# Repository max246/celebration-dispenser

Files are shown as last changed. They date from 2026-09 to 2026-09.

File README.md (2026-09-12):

# Celebration Dispenser




A button-triggered desktop celebration machine. Press the button and it dispenses
a treat (confetti, candy, sprinkles — your choice) via a stepper-driven mechanism
while a WS2812 LED strip runs a light show and a sound plays over a small
amplifier.

This repo has two halves:

| Folder | What's inside |
|---|---|
| [`hardware/`](hardware/) | 3D-printable STL parts (finger-wheel dispenser) + bill of materials + assembly guide |
| [`firmware/`](firmware/) | ESP32-S2 firmware (PlatformIO / Arduino) that runs the dispenser |

## How it works

```
        [ push button ]
              │  press
              ▼
    ┌──────────────┐   UART+step/dir   ┌──────────┐
    │  ESP32-S2    │ ────────────────▶ │ TMC2209  │─▶ NEMA 17 ─▶ finger wheel
    │  Feather     │ ◀──── DIAG stall ─┘ (auto-unjam on jam)
    │  (WiFi)      │ ────────────────▶ WS2812 strip ─▶ light show
    │              │ ──I2S──▶ MAX98357A ─▶ speaker ─▶ audio (from on-board flash)
    └──────────────┘
```

On a button press the ESP32-S2 runs a single **celebration sequence**: the
TMC2209 turns the finger wheel to dispense a portion (backing off and retrying if
StallGuard detects a jam), a rainbow sweeps the LED strip, and a sound plays from
on-board flash through the MAX98357A — all at the same time — then it returns to
idle.

## Quick start

1. **Print & wire the hardware** — see [`hardware/README.md`](hardware/README.md)
   and the wiring diagram in [`docs/WIRING.md`](docs/WIRING.md).
2. **Flash the firmware** — see [`firmware/README.md`](firmware/README.md). Bench-test
   the motor first with `pio run -e motortest -t upload`.
3. Power it up, press the button, celebrate.

## Tuning

Almost everything you'll want to change (dispense amount, speed, stall
sensitivity, LED count, volume, GPIO pins) lives in
[`firmware/include/config.h`](firmware/include/config.h); the celebration and
idle sounds are 16-bit WAV files in `firmware/data/` (uploaded with
`pio run -t uploadfs`). The printable parts and assembly guide live in
[`hardware/`](hardware/).

## License

[MIT](LICENSE) © Christian Bianchini. Note the bundled audio in `music/` /
`firmware/data/` is git-ignored and not covered by this license — supply your
own sounds.

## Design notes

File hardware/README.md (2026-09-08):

# Hardware

3D-printable parts and assembly for the Celebration Dispenser.

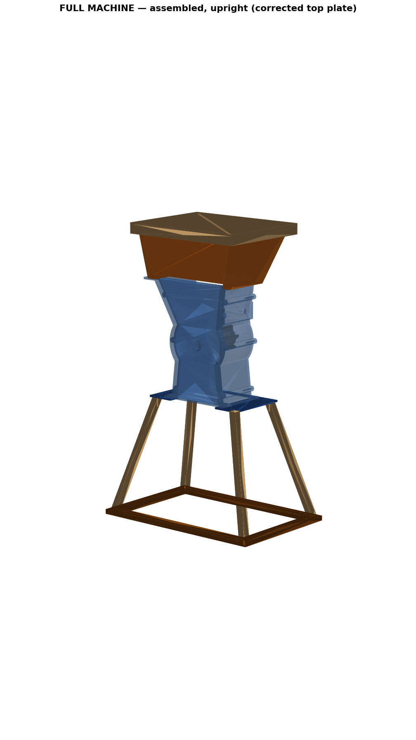
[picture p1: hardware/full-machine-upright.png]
Full machine — assembled, upright


The mechanism is a **finger wheel**: a printed wheel fitted with flexible
zip-tie "fingers" spins inside a housing, driven by the stepper. Candy sits in
the hopper above; the sweeping fingers agitate it and meter it through the
housing outlet. One button press = one dispense.

The fingers reach out to a wide annulus so they sweep close to the housing wall
(this is the `v5` wheel — cross-section below):

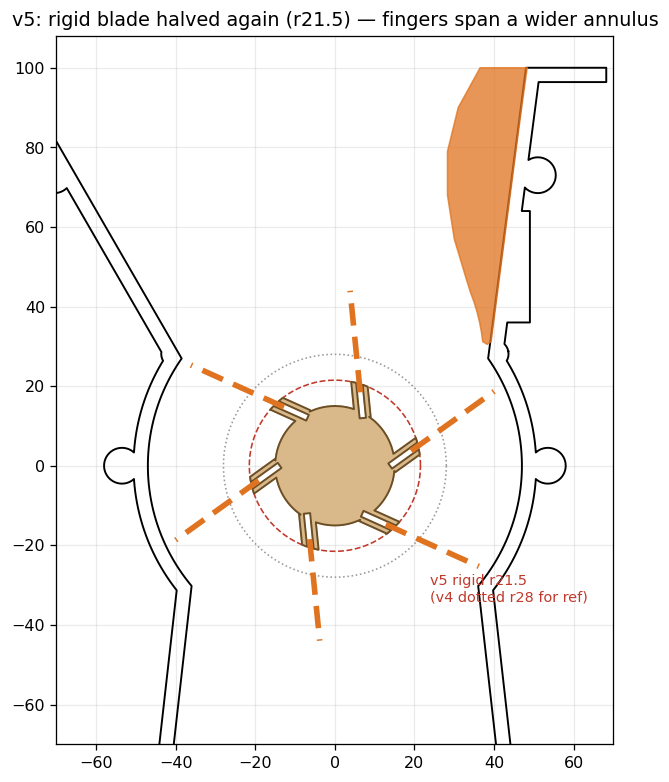
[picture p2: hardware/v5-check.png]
v5 finger-wheel cross-section


## Parts to print

Files in [`stl/`](stl/), with measured bounding boxes so you can check they fit
your printer's bed. Preview renders are in [`stl/previews/`](stl/previews/).

| File | Print qty | Size X×Y×Z (mm) | Role |
|---|---|---|---|
| `housing-main-608.stl` | 1 | 174 × 195 × 92  | Main housing; holds the wheel + 608 bearings |
| `housing-lid-608.stl` | 1 | 174 × 195 × 10  | Housing lid (6× M3×8) |
| `rear-bearing-block.stl` | 1 | 40 × 40 × 10 | Rear 608-bearing block; supports the shaft's back end |
| `rejector-ramp-v2.stl` | 1 | 20 × 70 × 80 | Rejector ramp inside the housing (sheds excess candy) |
| `vane-wheel-v5-half-blade.stl` | 1 | 90 × 90 × 80 | Finger wheel — takes the zip-tie fingers |
| `wheel-drive-pinion-12T.stl` | 1 | 21 × 21 × 20 | 12T pinion on the NEMA 17 shaft |
| `wheel-driven-gear-36T-v2.stl` | 1 | 57 × 57 × 28 | 36T gear on the 8 mm wheel shaft (3:1) |
| `wheel-motor-bracket-v5-counterbore.stl` | 1 | 117 × 40 × 26 | Motor bracket (holds the NEMA 17) |
| `hopper-extension-onepiece.stl`  | 1 | 204 × 94 × 150  | Hopper body; bolts to the housing mouth |
| `hopper-lid.stl` | 1 | 212 × 18 × 166  | Hopper lid (friction fit, no hardware) |
| `stand-top-plate.stl` | 1 | 184 × 106 × 3 | Plate the housing mounts to |
| `stand-leg-single.stl` | **4** | 70 × 200 × 57 | Stand leg — **print 4** (1 + mirror 3 in your slicer) |
| `stand-bottom-frame.stl` | 1 | 300 × 8 × 200 | Base frame tying the legs together |

> `housing-main` and the hopper are large (≈195–212 mm on their longest edge) —
> confirm they fit your build plate before slicing.

### Suggested print settings

- **Material:** PLA is fine indoors; PETG if it'll see any heat/sun.
- **Layer height:** 0.2 mm.
- **Walls / top / bottom:** 3 perimeters, 4 top/bottom layers.
- **Infill:** 20–30% (more for the finger wheel — it takes the load).
- **Supports:** likely needed on the housing (bearing pockets / overhangs) and
  possibly the hopper mouth — check each part in your slicer.

## Bill of materials (non-printed)

### Electronics

| Item | Qty | Notes |
|---|-----|---|
| Adafruit ESP32-S2 Feather | 1 | WiFi + 2 MB PSRAM (for streamed audio)  |
| NEMA 17 stepper motor | 1 | Drives the finger wheel |
| TMC2209 stepper driver | 1 | Silent; StallGuard stall-detect for auto-unjam |
| MAX98357A I2S amplifier | 1 | Plays the streamed celebration audio |
| Speaker, 4–8 Ω | 1 | To the MAX98357A output |
| WS2812 / NeoPixel strip | 1 | 16 px default (see `firmware/config.h`) |
| Momentary push button | 1 | |
| 12 V power supply (≥1 A) | 1 | For the motor via the driver |
| 100 µF cap, 330–470 Ω + 1 kΩ resistors | 1ea | Driver VM cap; LED data line; TMC2209 UART |

Wiring and pin map: [`../firmware/README.md`](../firmware/README.md).

### Mechanical fasteners

| Item | Qty  | Where |
|---|---|---|
| Zip ties (~2.5 mm wide) | 30 | Wheel **fingers** — 24 mm proud, glued in the slots |
| Super glue (CA) | — | To fix the zip-tie fingers in their slots |
| 608 bearings (8 mm bore) | 2 | Front seat in the housing + one in the rear-bearing-block |
| 8 mm shaft | 1 | Rides in the 608 bearings |
| M3 screws | 4 | Rear-bearing-block → housing rear |
| M3 grub / set screw | 3 | 1 locks the wheel, 2 lock the 36T gear, to the shaft |
| M3 × 25 screws | 2 | Motor-bracket standoffs (bottom out on the lid) |
| M3 × 8 screws | 6 | Housing lid → housing |
| M4 bolt + nut | 4 | Hopper extension → housing mouth-flange  |
| M4 × 20 screws | 4 | Stand: up into the leg bottoms |
| M3 × 16 screws | 4 | Stand: top plate down into the leg tops  |

## Assembly

### Section 1 — Stand

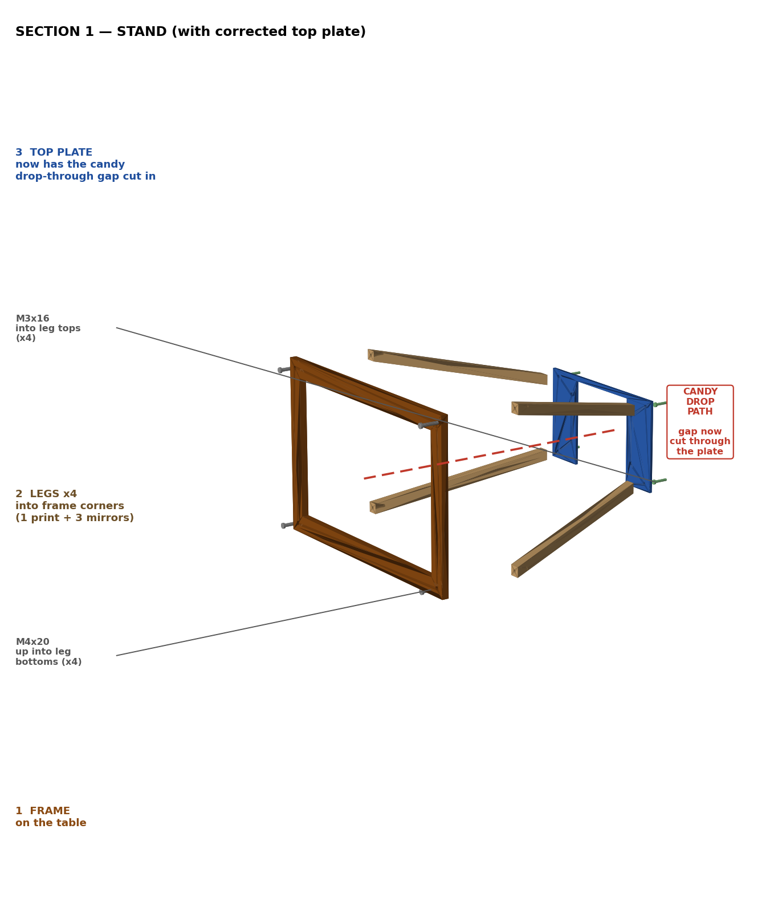
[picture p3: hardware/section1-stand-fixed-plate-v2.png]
Section 1 — Stand (with hardware)


1. **Frame** — lay `stand-bottom-frame` flat on the table.
2. **Legs ×4** — fit a leg into each frame corner and fasten from below with
   **M4 × 20** screws (×4). Print the leg once and **mirror 3 copies** in your
   slicer so all four corners match.
3. **Top plate** — set `stand-top-plate` onto the leg tops and secure with
   **M3 × 16** screws (×4).

### Section 2 — Housing core

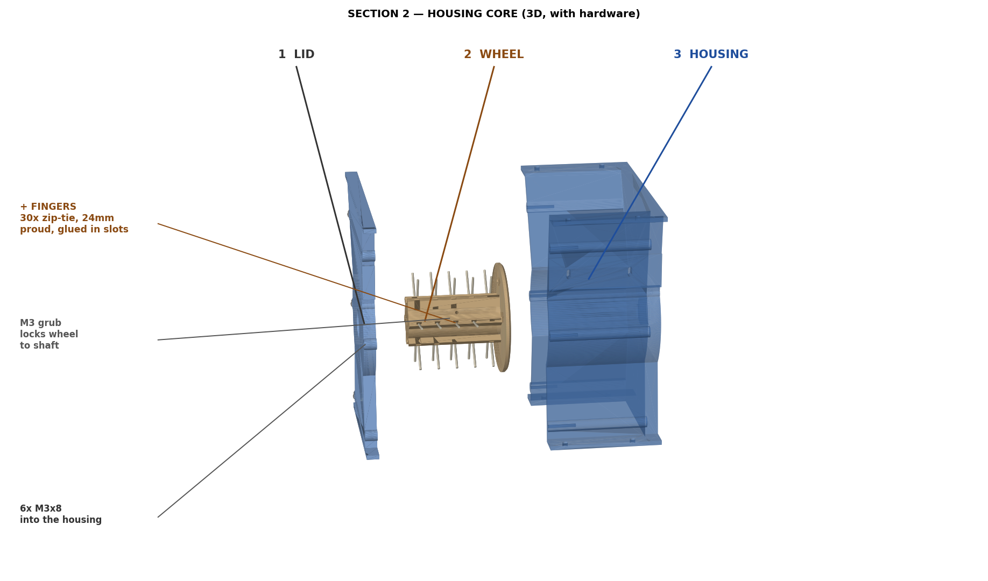
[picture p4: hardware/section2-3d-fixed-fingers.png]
Section 2 — Housing core (with hardware)


1. **Fingers** — push **30 zip ties** into the wheel's slots so ~**24 mm**
   stands proud, and **glue** them in place.
2. **Shaft + bearings** — seat one **608 bearing** in the housing (front) and
   the other in `rear-bearing-block`, then run the **8 mm shaft** through both.
   Screw the rear-bearing-block to the back of the housing (**4× M3**).
3. **Finger wheel** — mount the wheel on the shaft and lock it with the
   **M3 grub screw**.
4. **Close the lid** — `housing-lid-608` onto `housing-main-608` with
   **6× M3×8**, leaving the 8 mm shaft protruding for the drive train.

### Section 2b — Drive train

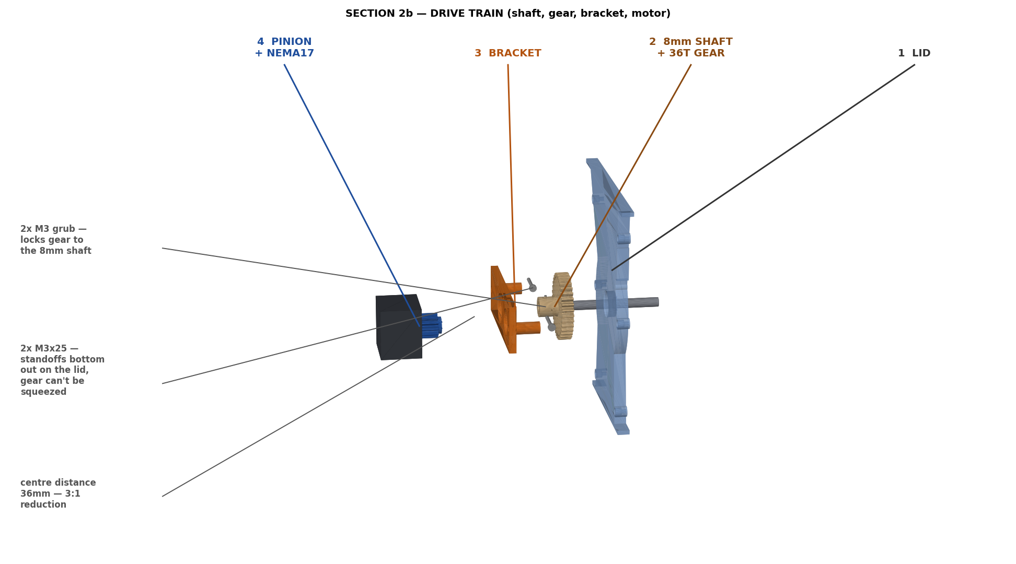
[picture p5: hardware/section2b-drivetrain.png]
Section 2b — Drive train (shaft, gear, bracket, motor)


1. **36T gear** — slide `wheel-driven-gear-36T-v2` onto the protruding 8 mm
   shaft and lock it with **2× M3 grub** screws.
2. **12T pinion** — fit `wheel-drive-pinion-12T` onto the NEMA 17 shaft.
3. **Bracket + motor** — bolt the motor to `wheel-motor-bracket-v5-counterbore`
   and fasten the bracket to the lid on **2× M3×25** standoffs. The standoffs
   bottom out on the lid so the gears can't be squeezed together; the pinion
   meshes with the 36T gear at a **36 mm centre distance** for a **3:1
   reduction**.

### Section 2c — Rejector ramp

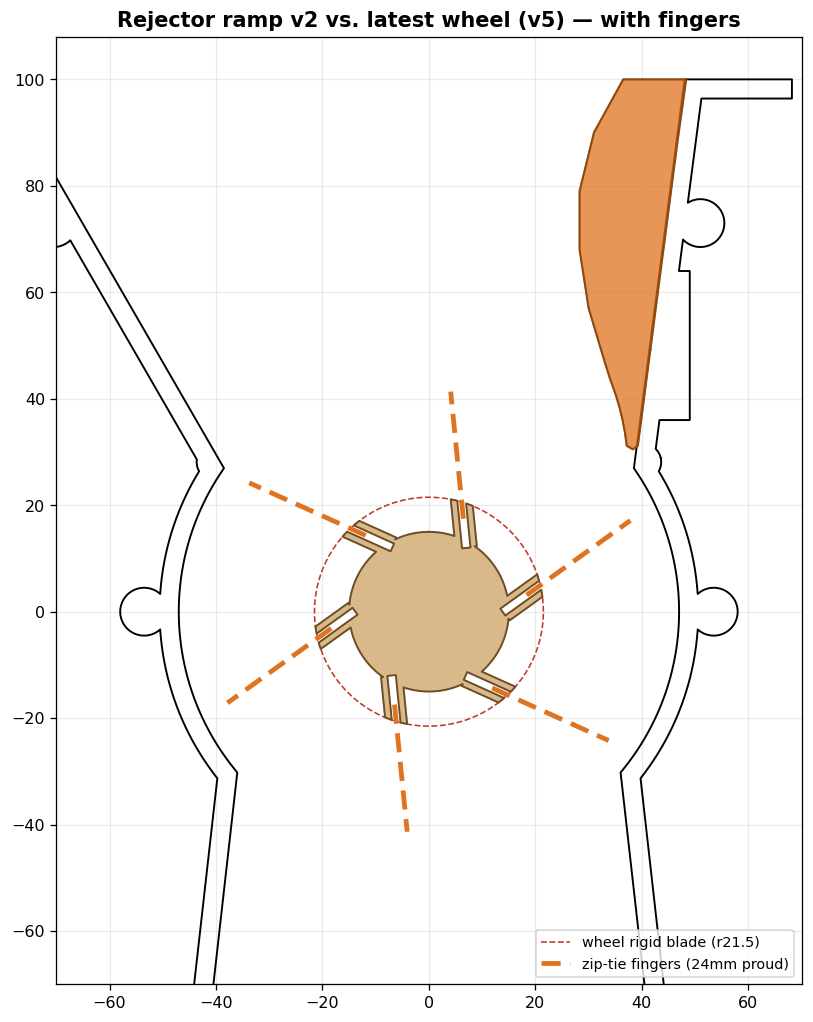
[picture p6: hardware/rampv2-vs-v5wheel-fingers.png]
Rejector ramp v2 vs. the v5 finger wheel


`rejector-ramp-v2` mounts against the housing's **feed-side wall** (top, below
the hopper mouth). Its lower tip sits **just outside the finger sweep** — the
zip-tie fingers reach ~24 mm proud of the r21.5 wheel — forming a narrowing gap.
As the wheel turns, surplus candy is pushed back up the ramp toward the hopper
while the fingers carry only a metered amount down to the outlet.

- Set the ramp tip to **just clear the finger tips** (no contact) — this gap is
  what sets the portion, so tune it against your candy size.
- The fit view shows no fasteners: the ramp seats against the wall (glue or a
  printed slot). Confirm how yours attaches and I'll note it here.

### Section 3 — Hopper stack

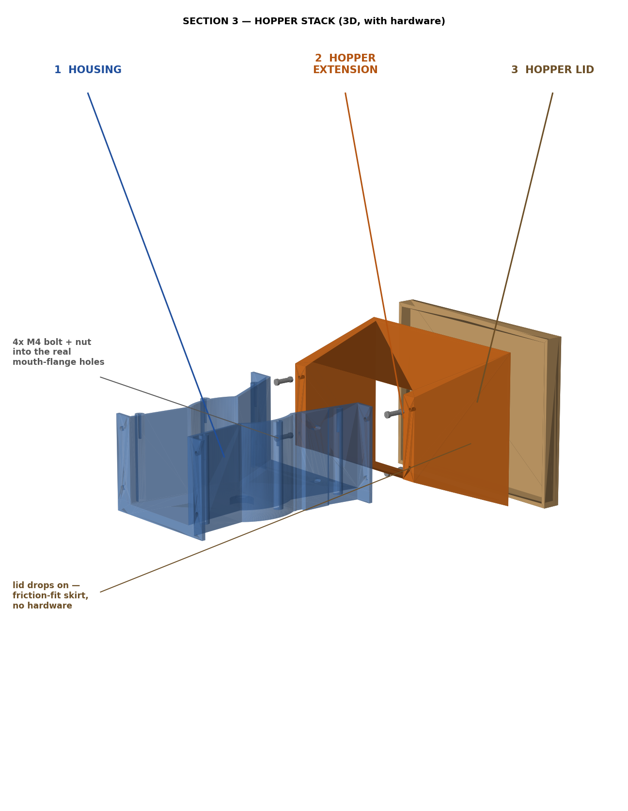
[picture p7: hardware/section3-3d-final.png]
Section 3 — Hopper stack (with hardware)


1. **Hopper extension** — bolt `hopper-extension-onepiece` to the housing's
   mouth-flange holes with **4× M4 bolt + nut**.
2. **Hopper lid** — `hopper-lid` just **drops on** (friction-fit skirt, no
   hardware).

### Final

Mount the housing on the stand's top plate, wire the electronics per the
firmware README (share all grounds), load candy, flash, and press the button.

## Tuning the dispense

Mechanics are fixed by the prints, but how much/how fast is dispensed is set in
the firmware — see [`../firmware/include/config.h`](../firmware/include/config.h):
`DISPENSE_REVS` (portion size), `STEPPER_MAX_SPEED` / `STEPPER_ACCEL` (speed),
`DISPENSE_CW` (direction), `MOTOR_CURRENT_MA`, and `STALL_THRESHOLD` (jam
sensitivity for the auto-unjam).

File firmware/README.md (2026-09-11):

# Firmware

ESP32-S2 firmware for the Celebration Dispenser, built with
[PlatformIO](https://platformio.org/) on the Arduino framework.

**Board:** Adafruit ESP32-S2 Feather (4 MB flash, 2 MB PSRAM).

## Layout

```
firmware/
├── platformio.ini            # board + pinned dependencies
├── data/                     # audio WAVs -> LittleFS (celebrate.wav, idle.wav)
├── include/
│   ├── config.h              # ALL tunables: pins, dispense, stall, LEDs, audio
│   └── secrets.h.example      # only for the streaming audio *test* (git-ignored)
└── src/
    ├── main.cpp              # button + celebration state machine
    ├── motor.{h,cpp}         # TMC2209 (UART) + AccelStepper + StallGuard unjam
    ├── audio_player.{h,cpp}  # raw WAV (preloaded to PSRAM) over I2S (MAX98357A)
    └── lights.{h,cpp}        # non-blocking WS2812 rainbow show
```

## First-time setup

Audio plays from on-board flash (no WiFi — see the note in **Behavior**). Put your
sounds in [`data/`](data/) and upload them once:

```bash
cd firmware
# put celebrate.wav and idle.wav in data/  (16-bit mono WAV — see data/README.md)
pio run -t uploadfs      # writes data/ to the LittleFS partition
pio run -t upload        # flash the firmware
```

The main firmware needs **no `secrets.h`** — that's only for the optional
streaming audio test.

## Wiring

Default pin map (edit in [`include/config.h`](include/config.h)). Pins are named
by the Feather's **silkscreen labels**. For a wiring diagram of the driver +
audio, see [`docs/WIRING.md`](../docs/WIRING.md).

### TMC2209 stepper driver

| Feather | TMC2209 | Notes |
|---|---|---|
| D5 | STEP | |
| D6 | DIR | |
| D9 | EN | active LOW; released when idle |
| D10 | DIAG | driver pulls HIGH on stall → triggers unjam |
| TX | PDN_UART | **through a 1 kΩ resistor** |
| RX | PDN_UART | direct (single-wire UART node) |
| 3.3V | VIO | logic supply |
| GND | GND | common ground |

Also on the driver: **VM + GND** → motor supply (e.g. 12 V) with a **100 µF cap**
across them; coil pairs → **1A/1B, 2A/2B**; **MS1 + MS2 → GND** (sets UART address
`0b00`, matching `TMC_ADDRESS`). Set the run current with `MOTOR_CURRENT_MA` in
`config.h` (it's configured over UART — no Vref pot to tune).

### Audio — MAX98357A (I2S)

| Feather | MAX98357A | Notes |
|---|---|---|
| SCK | BCLK | |
| MO | LRC | word-select |
| MI | DIN | |
| USB/5V  | VIN | 2.5–5.5 V |
| GND | GND | |

Speaker (4–8 Ω) to the amp's **+ / –** screw terminals. Leave `SD` unconnected
(enabled) and `GAIN` unconnected for the default 9 dB.

### Button & LEDs

| Feather | To |
|---|---|
| D11 | push button → **GND** (internal pull-up) |
| D12 | WS2812 **DIN** (330–470 Ω in series) |

> ⚠️ Share **all grounds** (Feather, driver logic, motor supply, amp, LEDs).
> Don't power the motor from the Feather — use a dedicated motor supply.

## Build & flash

```bash
pio run                 # compile
pio run -t upload       # flash over USB (native USB CDC on the S2)
pio device monitor      # serial log @ 115200
```

On boot the serial log prints whether LittleFS mounted and the TMC2209 version
(`0x21` = UART link good).

## Bench test (motor)

Before wiring the whole thing, bring up just the TMC2209 + motor with the
standalone test in `src/tools/motor_test.cpp` — a separate PlatformIO env that
needs **no WiFi, audio, or `secrets.h`**:

```bash
pio run -e motortest -t upload
pio device monitor -e motortest
```

It prints the driver version (`0x21` = UART OK), jogs the wheel ±1 revolution,
and streams `speed` / `DIAG` / `SG_RESULT` so you can confirm motion and tune
`STALL_THRESHOLD` (push on the wheel and watch `SG_RESULT` drop toward 0 / `DIAG`
go HIGH). Wiring for this is the TMC2209 half of
[`docs/WIRING.md`](../docs/WIRING.md).

## Bench test (audio)

Two audio tools, both separate envs (wiring is the MAX98357A half of
[`docs/WIRING.md`](../docs/WIRING.md)):

- **`tonetest`** — the definitive amp/wiring check. Plays a clean 440 Hz sine
  straight to I2S, no WiFi/decode/library. If this is clean, the amp, speaker,
  and I2S wiring are all good.
  ```bash
  pio run -e tonetest -t upload
  ```
- **`wavtest`** — the real audio path: preloads a WAV into PSRAM and plays it
  from RAM, no WiFi/motor/button. This is how you verify the celebration/idle
  audio in isolation. Put a `data/idle.wav` first.
  ```bash
  pio run -e wavtest -t upload     # flash + partition table
  pio run -e wavtest -t uploadfs   # upload data/idle.wav
  ```
- **`fstest` / `audiotest`** — diagnostic history: `fstest` plays MP3 from flash
  (decode can't keep up → crackles) and `audiotest` streams MP3 over WiFi
  (streaming crackles too). These are why the firmware uses raw WAV from PSRAM.
  Kept for reference / for an S3.

## Behavior

Audio is **16-bit WAV preloaded into PSRAM** and fed to I2S from RAM — no WiFi,
no MP3 decode, no flash access during playback. On the single-core S2 that's the
only path that stays clean (streaming and MP3 decode both crackle once their
buffer drains; playing raw PCM from RAM does not). Feeding is non-blocking, so
the motor and LEDs keep running while a sound plays.

While **idle**, `idle.wav` loops over the amp (at `IDLE_VOLUME`) — set
`ENABLE_IDLE_AUDIO = false` to disable it.

Press the button → one **celebration**, all at once:
- **Dispense:** the TMC2209 turns the finger wheel `DISPENSE_REVS` revolutions.
- **Auto-unjam:** if the candy jams, the motor stalls, DIAG goes HIGH, and the
  firmware backs off `UNJAM_REVERSE_STEPS` and retries — up to
  `UNJAM_MAX_RETRIES` times before giving up and logging a jam.
- **Lights:** a rainbow sweeps the WS2812 strip.
- **Audio:** the idle loop is interrupted and `celebrate.wav` plays once (at
  `CELEBRATION_VOLUME`); the idle loop resumes when it ends.

Presses during a celebration are ignored. When idle, the motor is de-energized
(silent, cool) unless `HOLD_TORQUE_WHEN_IDLE = true`.

## Tuning cheatsheet

| Want to… | Change in `config.h` |
|---|---|
| Dispense more/less | `DISPENSE_REVS` (wheel revolutions) |
| Change the gears | `GEAR_RATIO` (default 36T/12T = 3:1) |
| Dispense faster/slower | `STEPPER_MAX_SPEED`, `STEPPER_ACCEL` |
| Reverse direction | `DISPENSE_CW` |
| Motor current | `MOTOR_CURRENT_MA` |
| Stall sensitivity | `STALL_THRESHOLD` (higher = trips easier) |
| Unjam back-off / retries | `UNJAM_REVERSE_STEPS`, `UNJAM_MAX_RETRIES`|
| Quieter vs. more torque | `USE_STEALTHCHOP` |
| More/fewer LEDs, dimmer | `LED_COUNT`, `LED_BRIGHTNESS` |
| Volumes | `CELEBRATION_VOLUME`, `IDLE_VOLUME` (0–21) |
| Idle ambience on/off | `ENABLE_IDLE_AUDIO` |
| Sound files | `AUDIO_FILE`, `IDLE_FILE` (in `data/`, then `uploadfs`) |

## Notes

- Main-firmware dependencies (pinned in `platformio.ini`): **AccelStepper**,
  **Adafruit NeoPixel**, **TMCStepper**. Audio is raw WAV via the ESP-IDF I2S
  driver — no MP3 library. Platform is `espressif32@6.9.0` (arduino-esp32 2.0.x).
  The `audiotest`/`fstest` diagnostic envs still pull **ESP32-audioI2S** `2.0.6`.
- The S2 is single-core, so audio, step generation, and the LEDs share one CPU.
  Audio is fed non-blocking from PSRAM, so it coexists fine; if you ever hear a
  hiccup under very fast dispensing, lower `STEPPER_MAX_SPEED`.

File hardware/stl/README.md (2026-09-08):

# STL files

The printable parts for the Celebration Dispenser (a finger-wheel dispenser on
608 bearings). See [`../README.md`](../README.md) for the parts table, print
settings, bill of materials, and assembly.

| File | Role |
|---|---|
| `housing-main-608.stl` | Main housing; holds the finger wheel + bearings |
| `housing-lid-608.stl` | Housing lid |
| `rear-bearing-block.stl` | Rear 608-bearing block (supports shaft)|
| `rejector-ramp-v2.stl` | Rejector ramp inside the housing |
| `vane-wheel-v5-half-blade.stl` | Finger wheel — takes the zip-tie fingers |
| `wheel-drive-pinion-12T.stl` | 12T pinion on the motor shaft |
| `wheel-driven-gear-36T-v2.stl` | 36T gear on the 8 mm wheel shaft (3:1) |
| `wheel-motor-bracket-v5-counterbore.stl` | Motor bracket (holds the NEMA 17) |
| `hopper-extension-onepiece.stl`  | Hopper body |
| `hopper-lid.stl` | Hopper lid |
| `stand-top-plate.stl` | Plate the housing mounts to |
| `stand-leg-single.stl` | One stand leg — print ×4 (1 + mirror 3)|
| `stand-bottom-frame.stl` | Base frame |

Preview renders of each part are in [`previews/`](previews/).

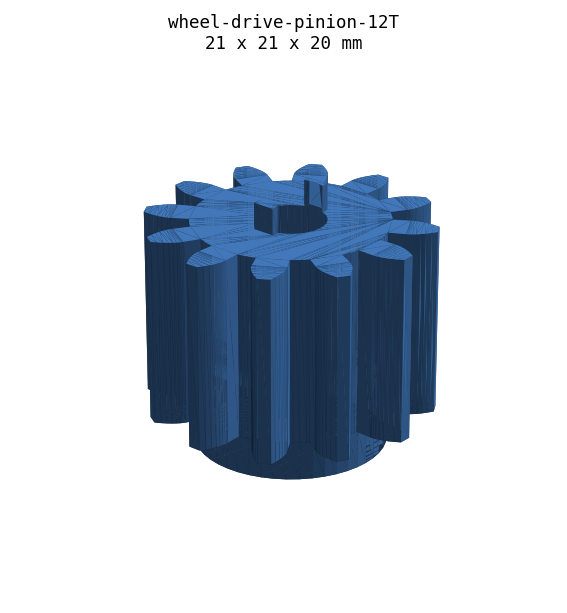
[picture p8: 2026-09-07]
hardware/stl/previews/wheel-drive-pinion-12T.png

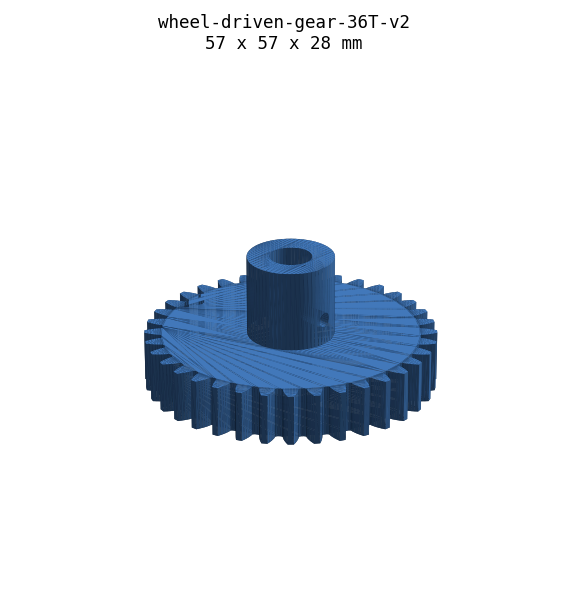
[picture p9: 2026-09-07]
hardware/stl/previews/wheel-driven-gear-36T-v2.png

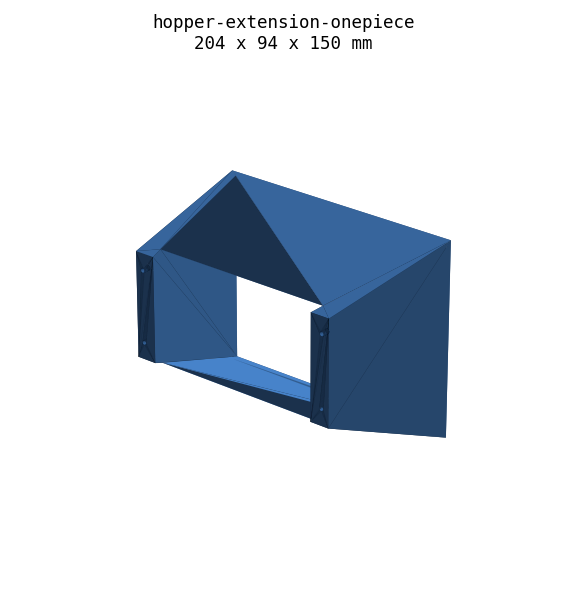
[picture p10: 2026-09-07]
hardware/stl/previews/hopper-extension-onepiece.png

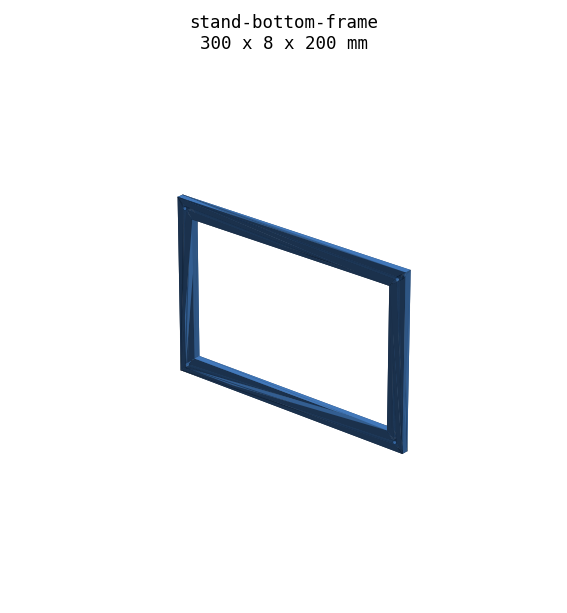
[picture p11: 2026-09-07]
hardware/stl/previews/stand-bottom-frame.png

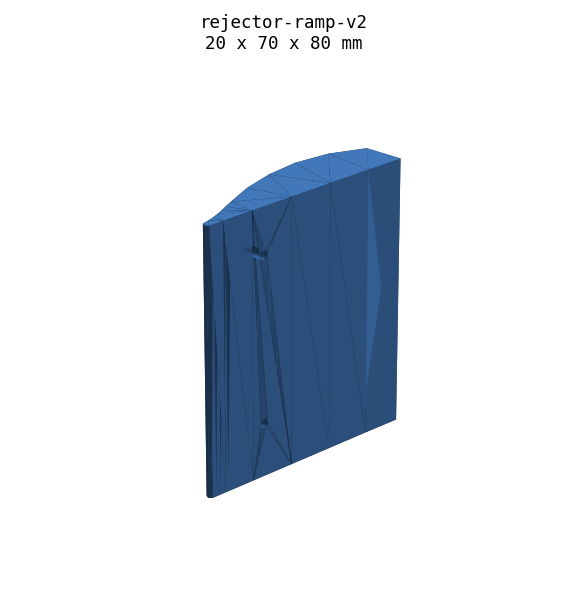
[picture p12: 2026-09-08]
hardware/stl/previews/rejector-ramp-v2.png

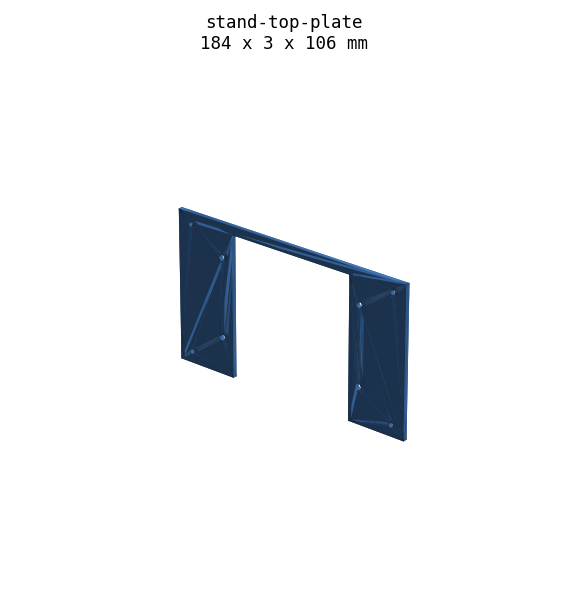
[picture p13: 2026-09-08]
hardware/stl/previews/stand-top-plate.png

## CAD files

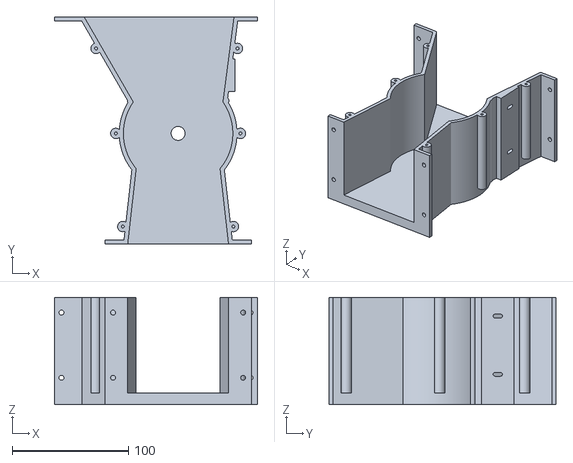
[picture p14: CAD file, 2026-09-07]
hardware/stl/housing-main-608.stl
174.4 x 195.0 x 92.0

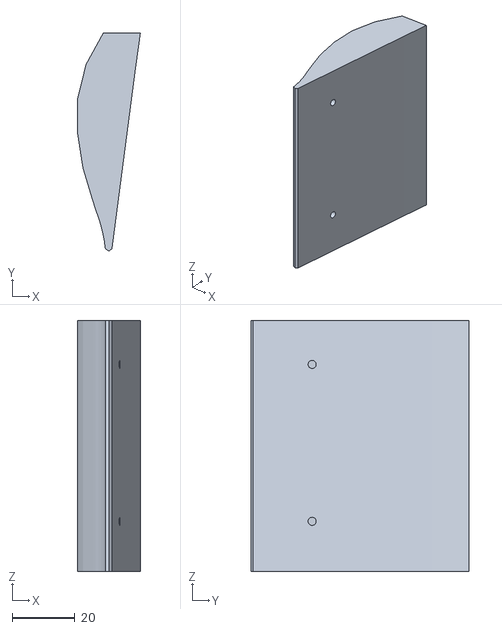
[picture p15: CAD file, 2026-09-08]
hardware/stl/rejector-ramp-v2.stl
20.0 x 69.5 x 80.0

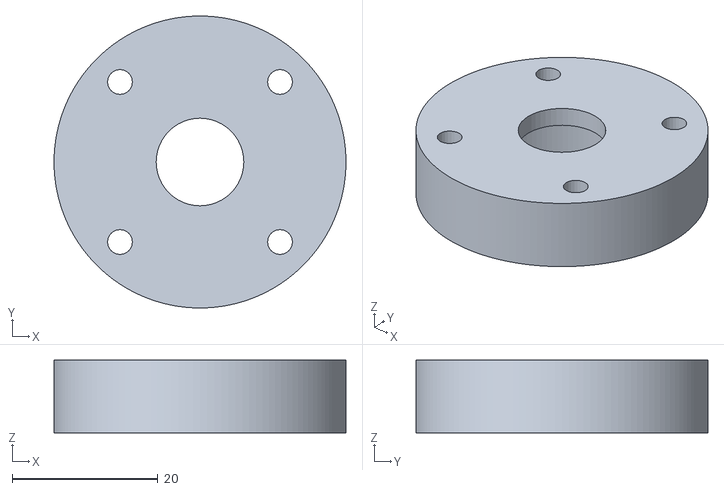
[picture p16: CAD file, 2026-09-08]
hardware/stl/rear-bearing-block.stl
40.0 x 40.0 x 10.0

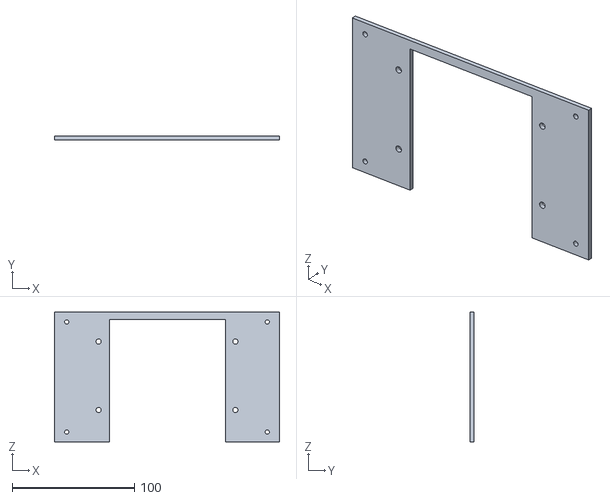
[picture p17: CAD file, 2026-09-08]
hardware/stl/stand-top-plate.stl
184.0 x 3.00 x 106.0

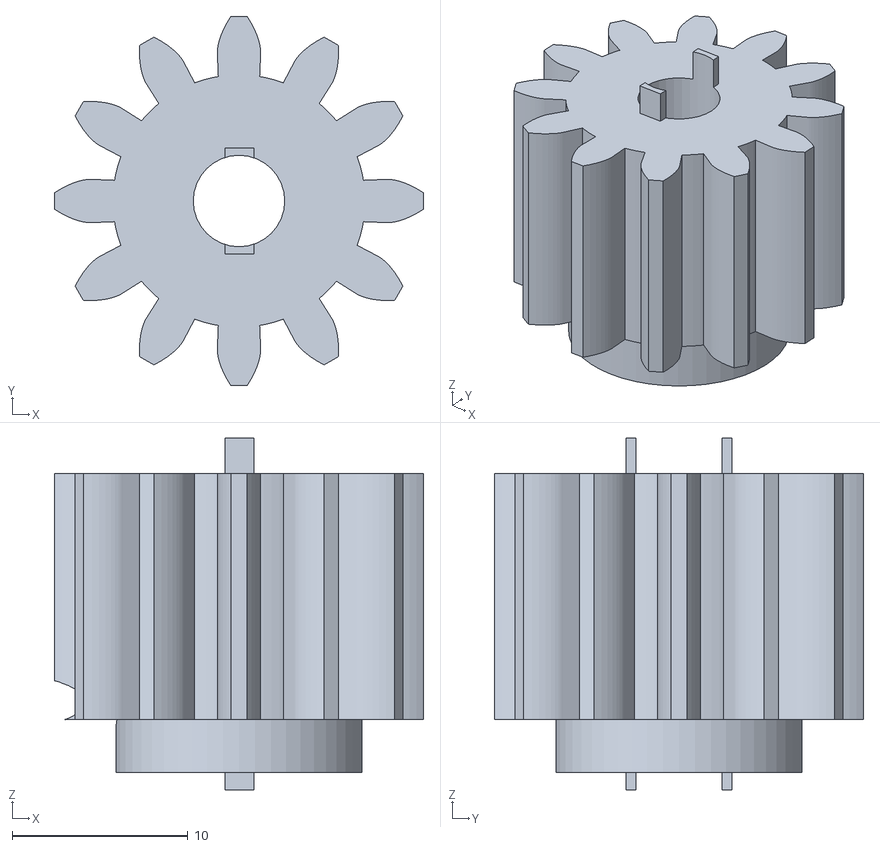
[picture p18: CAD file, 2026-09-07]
hardware/stl/wheel-drive-pinion-12T.stl
21.0 x 21.0 x 20.0

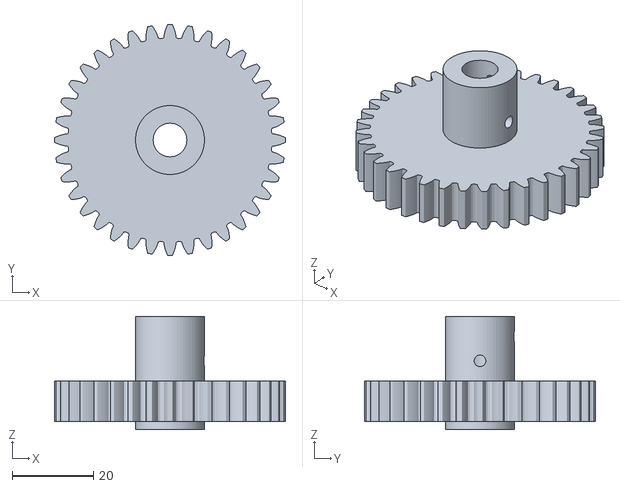
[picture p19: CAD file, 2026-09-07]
hardware/stl/wheel-driven-gear-36T-v2.stl
57.0 x 57.0 x 28.0

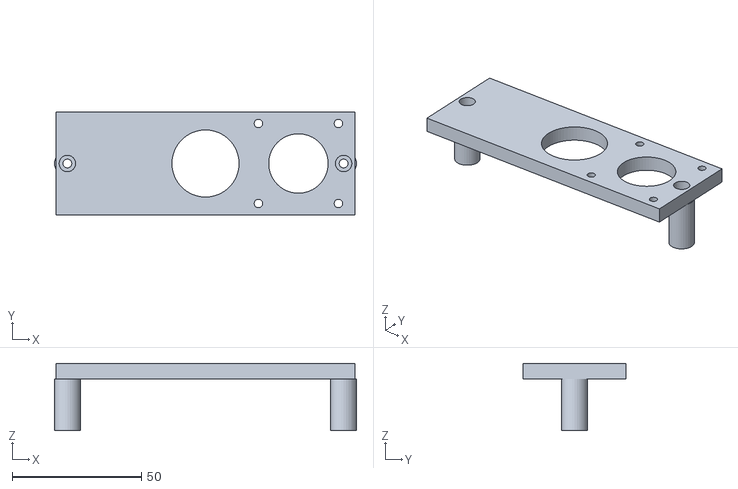
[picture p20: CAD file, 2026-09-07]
hardware/stl/wheel-motor-bracket-v5-counterbore.stl
117.0 x 40.0 x 26.0

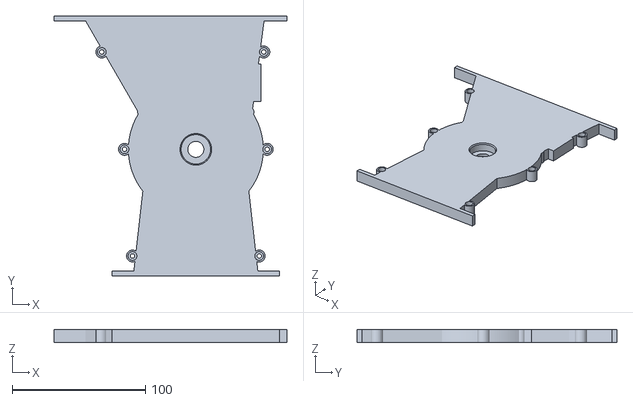
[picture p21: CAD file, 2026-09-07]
hardware/stl/housing-lid-608.stl
174.4 x 195.0 x 10.0

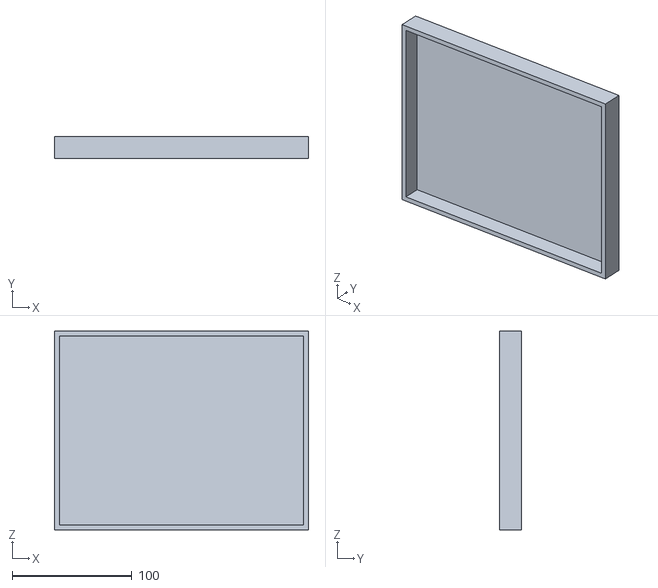
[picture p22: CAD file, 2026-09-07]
hardware/stl/hopper-lid.stl
212.0 x 18.0 x 166.0

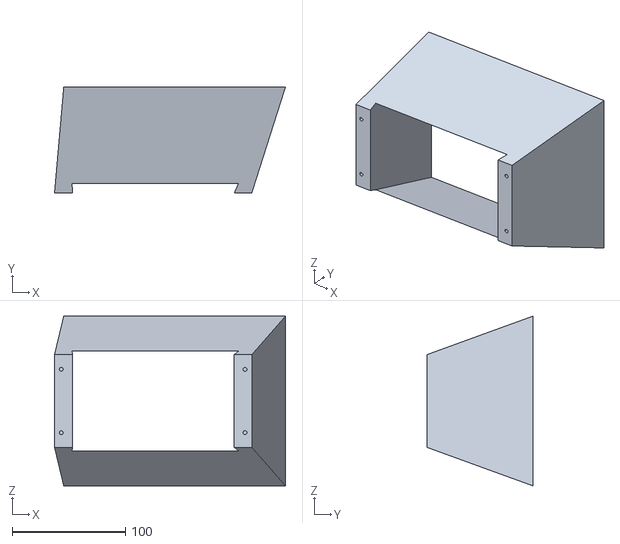
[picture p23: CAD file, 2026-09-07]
hardware/stl/hopper-extension-onepiece.stl
204.2 x 93.6 x 150.0

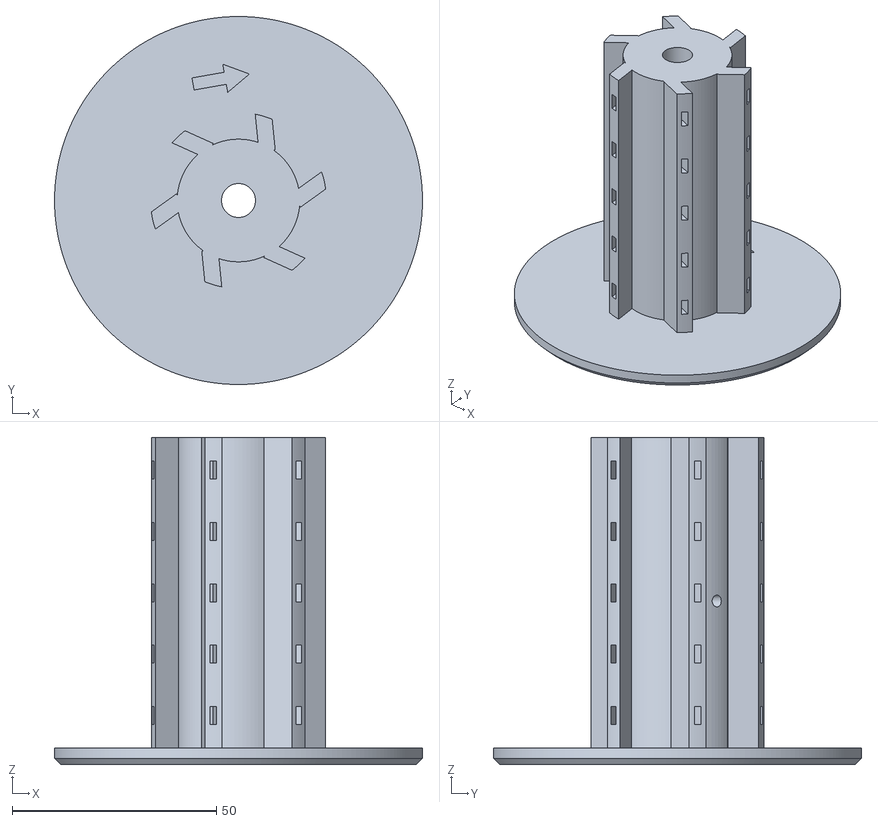
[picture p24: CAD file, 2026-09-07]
hardware/stl/vane-wheel-v5-half-blade.stl
90.0 x 90.0 x 80.0

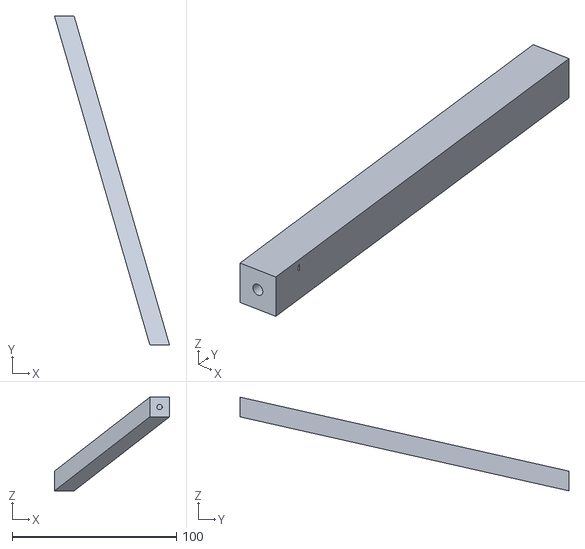
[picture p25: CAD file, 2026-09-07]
hardware/stl/stand-leg-single.stl
70.0 x 200.0 x 57.0

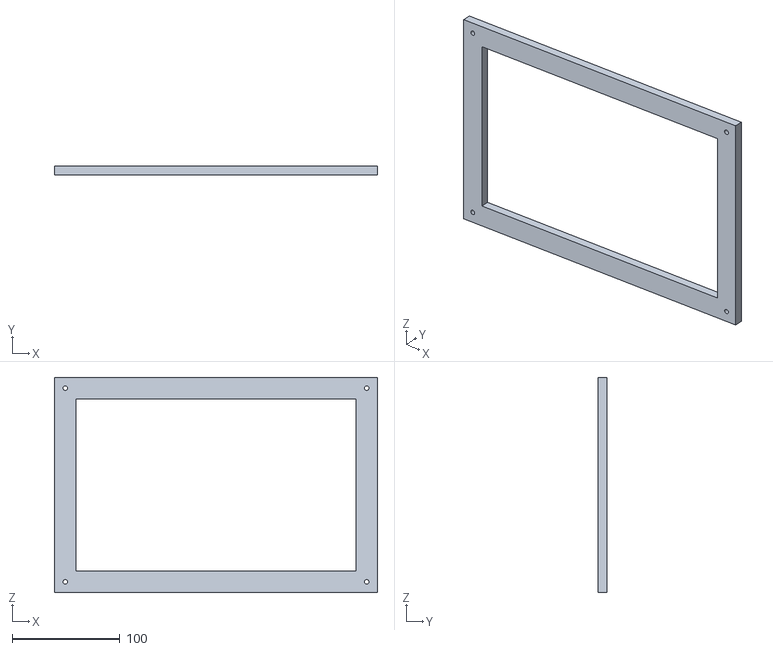
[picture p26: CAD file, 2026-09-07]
hardware/stl/stand-bottom-frame.stl
300.0 x 8.00 x 200.0

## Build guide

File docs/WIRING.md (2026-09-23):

# Wiring — motor driver + audio

Wiring for the **TMC2209** stepper driver and the **MAX98357A** I2S amplifier on
the Adafruit ESP32-S2 Feather. Pins match
[`firmware/include/config.h`](../firmware/include/config.h).

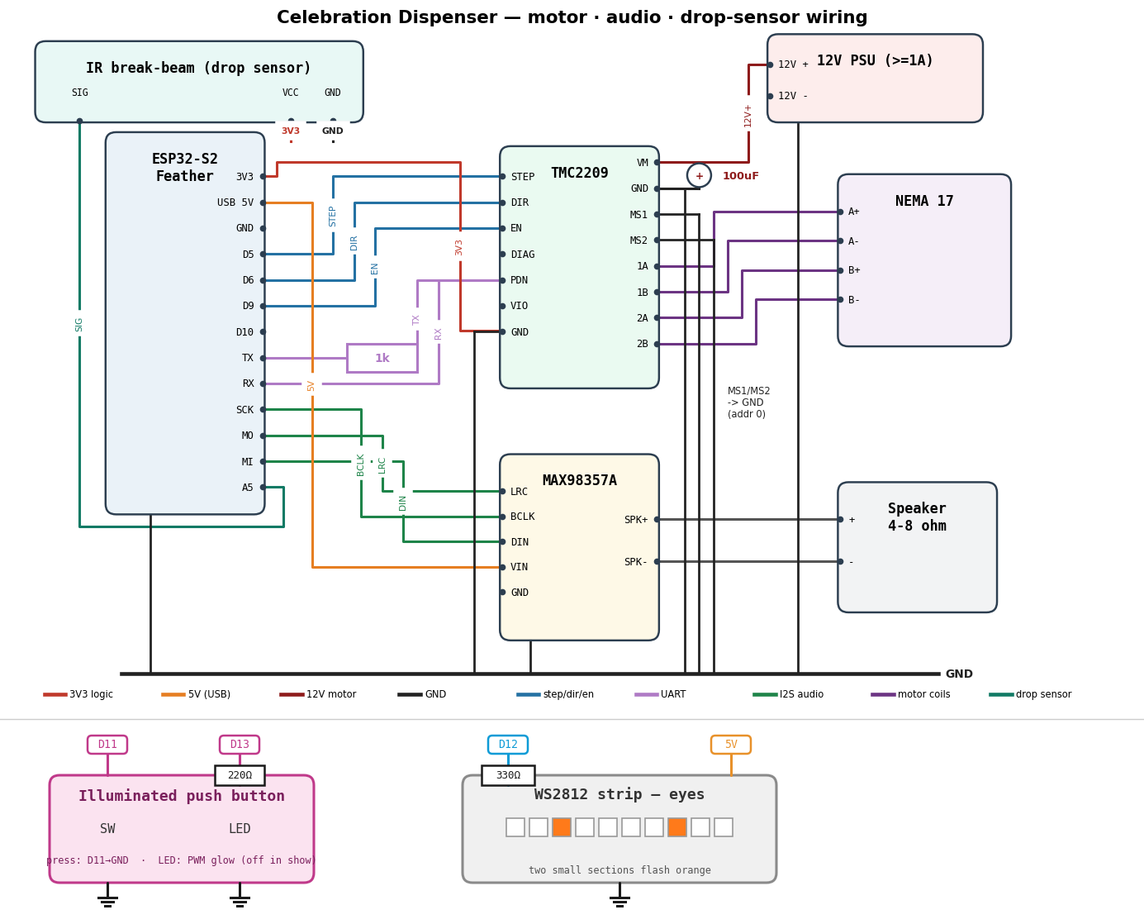
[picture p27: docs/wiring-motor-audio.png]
Motor driver + audio wiring


## Power rails

- **Feather** is powered over **USB** and provides the **3V3** (logic) and
  **USB/5V** rails used below.
- **Motor supply** is a separate **12 V** PSU into the driver's **VM/GND**, with
  a **100 µF** electrolytic cap right across VM↔GND. **Do not** run the motor
  from the Feather.
- **Tie all grounds together**: Feather GND, TMC2209 GND (logic + power), the
  12 V PSU minus, the MAX98357A GND, and the cap.

## TMC2209 ↔ Feather

| Feather | TMC2209  | Notes |
|---|---|---|
| D5 | STEP | |
| D6 | DIR | |
| D9 | EN | active LOW |
| D10 | DIAG | HIGH on stall (drives auto-unjam)  |
| TX | PDN_UART | **through a 1 kΩ resistor** |
| RX | PDN_UART | direct (single-wire UART node) |
| 3V3 | VIO | logic supply |
| GND | GND | common ground |

Driver power/config: **VM/GND** → 12 V (+100 µF cap); **MS1 + MS2 → GND** (UART
address `0b00`); coil pairs **1A/1B** and **2A/2B** → the motor.

## Motor (NEMA 17)

The two coils go to the two output pairs — **1A/1B** = one coil, **2A/2B** = the
other. If you don't know your motor's colour code, find a coil pair with a
multimeter (the two wires with continuity/low resistance are one coil), then:

| TMC2209 | Motor |
|---|---|
| 1A / 1B | coil A (A+ / A-) |
| 2A / 2B | coil B (B+ / B-) |

If the wheel spins the wrong way, either flip `DISPENSE_CW` in `config.h` or swap
one coil pair.

## MAX98357A ↔ Feather (I2S)

| Feather | MAX98357A | Notes |
|---|---|---|
| SCK | BCLK | |
| MO | LRC | word-select |
| MI | DIN | |
| USB/5V  | VIN | 2.5–5.5 V |
| GND | GND | |

Speaker (4–8 Ω) to the amp's **SPK+ / SPK–** terminals. Leave `SD` unconnected
(enabled) and `GAIN` unconnected for the default 9 dB.

## Illuminated push button ↔ Feather

The button has two independent parts: a momentary **switch** (two legs bridged
when pressed) and a built-in **LED** (bare ~2 V LED, no internal resistor).

| Feather | Button | Notes |
|---|---|---|
| D11 | switch leg 1 | `INPUT_PULLUP`; pressed = LOW |
| GND | switch leg 2 | the switch just shorts D11 → GND |
| D13 | LED + | **through a ~220 Ω resistor** (150–330 Ω OK) |
| GND | LED – | LED cathode to ground |

The LED runs on **LEDC hardware PWM**: a slow breathing glow while idle, and it
switches **off** for the duration of a celebration (the eyes take over the show).
D13 also drives the Feather's on-board red LED, so it mirrors the button
(harmless). If the button never triggers, the two switch legs may be a
permanently-connected pair — on a 4-pin tactile switch use legs on *opposite*
corners.

## WS2812 "eyes" strip ↔ Feather

A single chain of `LED_COUNT` (16) 5 V NeoPixels. During a celebration two small
contiguous sections (the eyes) flash orange; set their pixel ranges in
`config.h` (`EYE1_FIRST/LEN`, `EYE2_FIRST/LEN`) to match the physical layout.

| Feather | Strip | Notes |
|---|---|---|
| D12 | DIN | **through a 330–470 Ω** series resistor, near the strip |
| USB/5V  | 5V | 5 V power (external 5 V PSU for long strips; GND common) |
| GND | GND | common ground with the Feather |

Mind data **direction** — connect to the DIN end (arrows point away from DIN). A
**1000 µF** cap across the strip's 5V/GND helps with inrush. The ESP32-S2 data
line is 3.3 V; short runs usually work, but add a level shifter (74AHCT125) if
the strip is flaky.

## Bench test before the full build

Flash the standalone motor test to check the driver + motor in isolation (no
WiFi/audio needed) — see [Bench test](../firmware/README.md#bench-test-motor):

```bash
cd firmware
pio run -e motortest -t upload      # motor / TMC2209
pio run -e audiotest -t upload      # audio / MAX98357A (needs secrets.h WiFi)
pio run -e beamtest -t upload       # IR break-beam drop sensor (counts breaks)
pio run -e buttontest -t upload     # push button + its LED (breathe / solid)
pio run -e lightstest -t upload     # WS2812 strip (colour/dot/rainbow patterns)
pio device monitor -e motortest     # (or -e audiotest / beamtest / buttontest / lightstest)
```

- **Motor:** expect `TMC2209 version: 0x21` (UART OK), the wheel jogging back and
  forth, and a live `SG_RESULT` reading to tune `STALL_THRESHOLD`.
- **Audio:** expect WiFi to connect and a free sample MP3 to stream to the amp,
  ending with `[eof] Playback finished.`

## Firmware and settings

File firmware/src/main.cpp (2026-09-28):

#include <Arduino.h>

#include "audio_player.h"
#include "beam.h"
#include "button_led.h"
#include "config.h"
#include "lights.h"
#include "motor.h"

// Behaviour:
//   IDLE        button LED breathes; the idle sound chimes every
//               IDLE_AUDIO_PERIOD_MS (5 min). A button press starts a celebration.
//   CELEBRATING button LED off; the eyes flash orange; the celebration sound
//               plays; the motor dispenses (with anti-jam) until the drop sensor
//               sees a treat fall, or DISPENSE_TIMEOUT_MS (30 s) gives up. Once
//               the dispense is done and the sound has finished, it returns to IDLE.
enum State { IDLE, CELEBRATING };
static State state = IDLE;
static unsigned long celebrationStart = 0;
static unsigned long nextIdleAudioMs = 0;
static bool dispenseDone = false;
static bool idleGlowOn = false;  // FLASH section glowing yellow for the idle chime

// Fixed dispense time (used only when the drop sensor is off): how long to turn
// DISPENSE_REVS at the run speed.
static const unsigned long DISPENSE_FIXED_MS =
    (unsigned long)(DISPENSE_REVS * GEAR_RATIO * STEPS_PER_REV * MICROSTEPPING /
                    STEPPER_MAX_SPEED * 1000.0f);

// ---- button debounce state ----
static int lastReading = HIGH;
static int stableState = HIGH;
static unsigned long lastChangeMs = 0;

static bool buttonPressed() {
  const int reading = digitalRead(PIN_BUTTON);
  const unsigned long now = millis();
  if (reading != lastReading) {
    lastChangeMs = now;
    lastReading = reading;
  }
  if (now - lastChangeMs >= DEBOUNCE_MS && reading != stableState) {
    stableState = reading;
    if (stableState == LOW) return true;  // just pressed
  }
  return false;
}

static void scheduleNextIdleAudio() {
  nextIdleAudioMs = millis() + IDLE_AUDIO_PERIOD_MS;
}

static void startCelebration() {
  state = CELEBRATING;
  celebrationStart = millis();
  dispenseDone = false;
  beam::resetDrops();
  idleGlowOn = false;              // the eyes show replaces the idle glow
  buttonled::off();                // button goes dark for the show
  lights::startEyes();             // orange eyes flash
  audioplayer::playCelebration();  // takes over from the idle chime
  motor::run();                    // start dispensing (continuous, auto-unjam)
}

static void endCelebration() {
  state = IDLE;
  motor::stop();
  lights::off();
  buttonled::breathe();     // glowing button again
  scheduleNextIdleAudio();  // next idle chime in 5 min (no immediate replay)
}

// Decide when the dispensing part of a celebration is finished, and stop the
// motor. With the drop sensor: run until a treat drops, or DISPENSE_TIMEOUT_MS,
// or anti-jam gives up. Without it: turn a fixed portion.
static void serviceDispense() {
  if (dispenseDone) return;

  const unsigned long elapsed = millis() - celebrationStart;

  if (motor::jammedGaveUp()) {
    dispenseDone = true;
    Serial.println(F("dispense: jammed, gave up clearing"));
    return;
  }

  if (ENABLE_DROP_SENSOR) {
    if (beam::drops() > 0) {
      motor::stop();  // wheel off; the celebration keeps running until the audio ends
      dispenseDone = true;
      Serial.println(F("dispense: treat dropped (finishing the track)"));
    } else if (elapsed > DISPENSE_TIMEOUT_MS) {
      motor::stop();
      dispenseDone = true;
      Serial.println(F("dispense: no drop within 30 s (empty/refill?)"));
    }
  } else if (elapsed > DISPENSE_FIXED_MS) {
    motor::stop();
    dispenseDone = true;
    Serial.println(F("dispense: portion done"));
  }
}

void setup() {
  Serial.begin(115200);
  for (unsigned long _t = millis(); !Serial && millis() - _t < 8000;) delay(10);
  delay(300);
  pinMode(PIN_BUTTON, INPUT_PULLUP);

  lights::begin();
  motor::begin();
  beam::begin();
  buttonled::begin();
  audioplayer::begin();

  buttonled::breathe();     // idle glow from the start
  scheduleNextIdleAudio();  // first idle chime one period from boot

  Serial.println(F("Celebration Dispenser ready. Press the button!"));
}

void loop() {
  audioplayer::update();  // service the audio constantly
  beam::update();          // debounce the drop sensor

  const bool pressed = buttonPressed();

  switch (state) {
    case IDLE:
      buttonled::update();  // breathe
      lights::update();     // pulse the idle glow (no-op when the strip is off)
      if (ENABLE_IDLE_AUDIO && (long)(millis() - nextIdleAudioMs) >= 0) {
        audioplayer::playIdle();
        if (audioplayer::isIdlePlaying()) {
          lights::startIdleGlow();  // yellow glow for as long as the chime plays
          idleGlowOn = true;
        }
        scheduleNextIdleAudio();
      }
      if (idleGlowOn && !audioplayer::isIdlePlaying()) {
        lights::off();
        idleGlowOn = false;
      }
      if (pressed) {
        Serial.println(F("Celebrate!"));
        startCelebration();
      }
      break;

    case CELEBRATING: {
      motor::update();
      lights::update();
      serviceDispense();

      const unsigned long elapsed = millis() - celebrationStart;
      const bool audioDone = !audioplayer::isCelebrationPlaying();
      const bool minTimeUp = elapsed >= MIN_CELEBRATION_MS;

      if (dispenseDone && audioDone && minTimeUp) {
        endCelebration();
        Serial.println(F("Done. Ready for the next one."));
      }
      break;
    }
  }
}

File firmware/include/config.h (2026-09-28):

#pragma once

// ===========================================================================
//  Celebration Dispenser — configuration
//  Target board: Adafruit ESP32-S2 Feather (4 MB flash, 2 MB PSRAM)
//  Edit this file to retune the device.
// ===========================================================================

// Audio is 16-bit WAV preloaded into PSRAM and played from RAM (not streamed,
// not MP3) — the only path that stays clean on the single-core S2. Put your WAVs
// in firmware/data/ and upload them with `pio run -t uploadfs`. No WiFi, no
// secrets.h needed for the main firmware.

// ---- GPIO pin map (Adafruit ESP32-S2 Feather) -----------------------------
// Numbers are the raw GPIOs; the Feather silkscreen label is in the comment.
// TMC2209 (step/dir + UART):
static const int PIN_STEP   = 5;   // "D5"  -> TMC2209 STEP
static const int PIN_DIR    = 6;   // "D6"  -> TMC2209 DIR
static const int PIN_EN     = 9;   // "D9"  -> TMC2209 EN   (active LOW)
static const int PIN_DIAG   = 10;  // "D10" <- TMC2209 DIAG (HIGH on stall)
static const int PIN_TMC_TX = 39;  // "TX"  -> TMC2209 PDN_UART (via 1k)
static const int PIN_TMC_RX = 38;  // "RX"  <- TMC2209 PDN_UART

// Controls / feedback:
static const int PIN_BUTTON     = 11;  // "D11" push button to GND (INPUT_PULLUP)
static const int PIN_BUTTON_LED = 13;  // "D13" illuminated-button LED via ~220R
                                       //  (also drives the on-board red LED)
static const int PIN_LED        = 12;  // "D12" WS2812 strip data (330-470R in series)

// MAX98357A I2S audio amp:
static const int PIN_I2S_BCLK = 36;  // "SCK" -> MAX98357A BCLK
static const int PIN_I2S_LRC  = 35;  // "MO"  -> MAX98357A LRC (word select)
static const int PIN_I2S_DOUT = 37;  // "MI"  -> MAX98357A DIN

// ---- TMC2209 stepper driver ------------------------------------------------
static const float TMC_RSENSE   = 0.11f;   // sense resistor on most 2209 modules
static const uint8_t TMC_ADDRESS = 0b00;   // set by MS1/MS2 (both to GND = 0)
static const uint32_t TMC_BAUD  = 115200;  // UART baud to the driver
static const int  MOTOR_CURRENT_MA = 1500; // needs heatsink; must be <= motor rating
static const int  MICROSTEPPING    = 16;   // driver microsteps (set over UART)
static const bool USE_STEALTHCHOP  = true; // quiet mode (StallGuard4 still works)

// ---- Stepper / dispensing --------------------------------------------------
static const long STEPS_PER_REV = 200;     // 1.8°/step NEMA 17 = 200 full steps
// Gear reduction from motor to the finger wheel: 12T pinion -> 36T gear = 3:1.
// The motor turns GEAR_RATIO times for one wheel revolution.
static const float GEAR_RATIO   = 36.0f / 12.0f;
static const float DISPENSE_REVS = 1.0f;   // fixed portion used only when the drop sensor is OFF
static const bool  DISPENSE_CW   = false;   // false to reverse
// With the drop sensor ON, dispense runs until a treat drops, up to this long
// (30 s), then gives up (empty hopper / stuck candy).
static const unsigned long DISPENSE_TIMEOUT_MS = 30000;
// Dispense at the speed StallGuard was tuned at — SG_RESULT is speed-specific,
// so changing this means re-checking STALL_THRESHOLD with `motortest`.
static const float STEPPER_MAX_SPEED = 4000.0f;  // AccelStepper software ceiling; watch startup slip + re-tune stall
static const float STEPPER_ACCEL     = 3200.0f;  // microsteps/sec^2
// Release holding torque when idle? false = motor free-spins, silent, cooler.
static const bool  HOLD_TORQUE_WHEN_IDLE = false;

// ---- Stall detection / auto-unjam (StallGuard via SG_RESULT over UART) ------
// The DIAG pin didn't assert on this driver, so stalls are detected by reading
// SG_RESULT directly: free-running is high (~200 measured), a stall drops it
// toward 0. STALL_THRESHOLD is still written to the driver's SGTHRS register.
static const uint8_t  STALL_THRESHOLD  = 50;   // SGTHRS (driver register)
static const uint16_t SG_STALL_LEVEL   = 70;   // stall when SG_RESULT below this
static const int      SG_STALL_CONFIRM = 2;    // consecutive low reads to confirm
static const unsigned long SG_POLL_MS  = 30;   // how often to read SG_RESULT
// Only evaluate a stall at cruise speed — StallGuard is invalid during accel.
static const unsigned long STALL_IGNORE_MS = 120;
static const float STALL_MIN_SPEED         = 0.9f * STEPPER_MAX_SPEED;
// On a jam: back off this many microsteps, then resume forward (wiggle to clear).
static const long UNJAM_REVERSE_STEPS = (long)(0.25f * STEPS_PER_REV * MICROSTEPPING);
// Keep trying to clear a jam (reverse+forward) for up to this long, then give up.
static const unsigned long ANTIJAM_TIMEOUT_MS = 5000;
// Running forward stall-free for this long counts the jam as cleared.
static const unsigned long JAM_CLEAR_MS = 1000;
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

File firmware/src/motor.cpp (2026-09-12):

#include <AccelStepper.h>
#include <Arduino.h>
#include <TMCStepper.h>

#include "config.h"
#include "motor.h"

// Continuous-run dispense engine with automatic anti-jam. Motion is constant
// speed (runSpeed / runSpeedToPosition) because StallGuard needs steady step
// timing. Stalls are detected by polling SG_RESULT over UART (the DIAG pin
// didn't assert on this driver).

namespace {

HardwareSerial& kTmcSerial = Serial1;
TMC2209Stepper driver(&kTmcSerial, TMC_RSENSE, TMC_ADDRESS);
AccelStepper stepper(AccelStepper::DRIVER, PIN_STEP, PIN_DIR);

enum Phase { STOPPED, FORWARD, REVERSING };
Phase phase = STOPPED;

bool gaveUp = false;
unsigned long fwdStartMs = 0;   // when the current forward run began (accel/settle window)
unsigned long jamStartMs = 0;   // start of the current jam episode (0 = none)

// SG_RESULT polling
int sgLowCount = 0;
unsigned long lastSgPollMs = 0;

void enableDriver(bool on) { digitalWrite(PIN_EN, on ? LOW : HIGH); }

float fwdSpeed() { return DISPENSE_CW ? STEPPER_MAX_SPEED : -STEPPER_MAX_SPEED; }

void startForward() {
  stepper.setSpeed(fwdSpeed());
  phase = FORWARD;
  fwdStartMs = millis();
}

// Stall via SG_RESULT, valid only at cruise speed and past the settle window.
bool stallDetected() {
  if (millis() - fwdStartMs < STALL_IGNORE_MS) { sgLowCount = 0; return false; }
  if (fabs(stepper.speed()) < STALL_MIN_SPEED) { sgLowCount = 0; return false; }
  if (millis() - lastSgPollMs < SG_POLL_MS) return false;
  lastSgPollMs = millis();
  if (driver.SG_RESULT() < SG_STALL_LEVEL) {
    if (++sgLowCount >= SG_STALL_CONFIRM) { sgLowCount = 0; return true; }
  } else {
    sgLowCount = 0;
  }
  return false;
}

void beginReverse() {
  const long back = DISPENSE_CW ? -UNJAM_REVERSE_STEPS : UNJAM_REVERSE_STEPS;
  stepper.move(back);                    // relative back-off from here
  stepper.setSpeed(STEPPER_MAX_SPEED);   // magnitude; direction from the target
  phase = REVERSING;
}

}  // namespace

void motor::begin() {
  pinMode(PIN_EN, OUTPUT);
  enableDriver(false);
  pinMode(PIN_DIAG, INPUT);

  kTmcSerial.begin(TMC_BAUD, SERIAL_8N1, PIN_TMC_RX, PIN_TMC_TX);
  driver.begin();
  driver.toff(4);
  driver.blank_time(24);
  driver.rms_current(MOTOR_CURRENT_MA);
  driver.microsteps(MICROSTEPPING);
  driver.pwm_autoscale(true);
  driver.en_spreadCycle(!USE_STEALTHCHOP);
  driver.TCOOLTHRS(0xFFFFF);
  driver.SGTHRS(STALL_THRESHOLD);

  stepper.setMaxSpeed(STEPPER_MAX_SPEED);
  stepper.setEnablePin(-1);  // we manage EN ourselves

  Serial.print(F("TMC2209 version: 0x"));
  Serial.println(driver.version(), HEX);  // 0x21 when the UART link is good
}

void motor::run() {
  gaveUp = false;
  jamStartMs = 0;
  enableDriver(true);
  startForward();
}

void motor::stop() {
  phase = STOPPED;
  if (!HOLD_TORQUE_WHEN_IDLE) enableDriver(false);
}

void motor::update() {
  switch (phase) {
    case STOPPED:
      break;

    case FORWARD:
      stepper.setSpeed(fwdSpeed());
      stepper.runSpeed();  // continuous forward at constant speed

      if (stallDetected()) {
        if (jamStartMs == 0) jamStartMs = millis();
        if (millis() - jamStartMs > ANTIJAM_TIMEOUT_MS) {
          Serial.println(F("anti-jam: gave up (still stuck)"));
          gaveUp = true;
          motor::stop();
        } else {
          Serial.println(F("jam — backing off to clear"));
          beginReverse();
        }
      } else if (jamStartMs != 0 && millis() - fwdStartMs > JAM_CLEAR_MS) {
        jamStartMs = 0;  // ran forward stall-free long enough — jam cleared
      }
      break;

    case REVERSING:
      stepper.runSpeedToPosition();
      if (stepper.distanceToGo() == 0) startForward();  // resume dispensing
      break;
  }
}

bool motor::isRunning() { return phase != STOPPED; }
bool motor::jammedGaveUp() { return gaveUp; }

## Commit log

2026-09-07 initial celebration dispenser: firmware + hardware + assembly guide
    Firmware (ESP32-S2 Feather, PlatformIO/Arduino):
    - Button-triggered celebration: dispense + WS2812 light show + streamed audio
    - TMC2209 over UART with StallGuard DIAG stall-detect and auto-unjam retry
    - MAX98357A I2S audio streamed from a URL, plus a looping idle ambience
    - All tunables in config.h; WiFi creds + URLs in git-ignored secrets.h
    Hardware (finger-wheel dispenser):
    - STL parts + 3D preview renders
    - Assembly guide with Section 1-3 diagrams and full-machine view
    - Bill of materials (electronics + mechanical fasteners)
    Claude-Session: https://claude.ai/code/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
    [hopper-extension-onepiece.stl, hopper-lid.stl, housing-lid-608.stl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]
2026-09-07 add drivetrain: 12T pinion, 36T gear, motor bracket (3:1 reduction)
    Hardware:
    - New STL parts (pinion, gear, motor bracket) + preview renders
    - Section 2b drive-train assembly diagram and steps
    - BOM: gear grub screws + M3x25 motor-bracket standoffs
    Firmware:
    - Add GEAR_RATIO (36T/12T = 3:1) so DISPENSE_REVS stays wheel revolutions
    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
    [wheel-drive-pinion-12T.stl, wheel-driven-gear-36T-v2.stl, wheel-motor-bracket-v5-counterbore.stl]
2026-09-08 regenerate STL previews for updated stand-top-plate
    - Re-render all part previews + contact sheet from current STLs
    - Update stand-top-plate dims (184x106x3) after the fixed-plate revision
    - Point Section 1 assembly image at the renamed render
    Claude-Session: https://claude.ai/code/session_014YpfzHKte14D5BQrjfcig2
    [stand-top-plate.stl]
2026-09-08 add rear-bearing-block and rejector-ramp parts + previews
    - New STLs with preview renders; contact sheet rebuilt (13 parts)
    - Listed both in the hardware + stl parts tables
    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
    [rear-bearing-block.stl, rejector-ramp-v2.stl]
2026-09-08 assembly: add rear-bearing-block + rejector-ramp steps
    - Shaft now seats a 608 in the housing (front) and one in the rear-bearing-block
    - Rear block screwed to housing rear (4x M3); BOM updated
    - Section 2c placeholder for the rejector ramp pending the fit diagram
    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
2026-09-08 Section 2c: add rejector-ramp fit view and placement
    - Ramp seats on the housing feed-side wall, tip just clearing the finger sweep
    - Gap sets the metered portion; tune to candy size
    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
2026-09-08 docs: add Print qty column to parts table (legs = 4)
    Make print quantities explicit; the stand needs 4 legs (1 printed + 3 mirrored).
    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
2026-09-10 add motor bench-test env + motor/audio wiring diagram
    - src/tools/motor_test.cpp: standalone TMC2209 + NEMA17 bring-up
    (no WiFi/audio/secrets); prints version, jogs wheel, streams SG_RESULT
    - platformio.ini: new `motortest` env; main build excludes tools/
    Docs:
    - docs/WIRING.md + wiring-motor-audio.png (TMC2209 + MAX98357A)
    - Bench-test section in firmware README; cross-links from READMEs
    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
2026-09-11 wiring: draw the 1k UART resistor as a labelled box
    Was a text label hidden behind the wire; now a clear boxed "1k" on the TX line.
    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
2026-09-11 wiring: shift 1k clear of 5V line; draw 100uF cap as a circle
    - 1k resistor box no longer touches the 5V wire
    - 100uF shown as a proper capacitor circle across VM<->GND (was text on the line)
    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
2026-09-11 wiring: clear labels for 100uF cap and MS1/MS2 note
    - 100uF label placed beside the cap in open space (12V wire routed clear)
    - MS1/MS2 -> GND note moved off the wire cluster
    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
2026-09-11 wiring: lift 3V3 run above the STEP rail so STEP is visible
    3V3 and STEP shared the top rail height; 3V3 now routes just above it.
    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
2026-09-11 add standalone audio streaming test env
    - src/tools/audio_test.cpp: WiFi + MAX98357A streaming a free sample MP3
    (SoundHelix), with [info]/[id3]/[eof] diagnostics and HTTP radio alternates
    - platformio.ini: new `audiotest` env (builds only that file)
    - Document audio bench test in firmware README + docs/WIRING.md
    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
2026-09-11 audio: disable WiFi modem sleep to stop streaming crackle
    - WiFi.setSleep(false) in audio_player + audio_test (single-core S2 underruns)
    - audio_test prints PSRAM size / free heap / RSSI for diagnostics
    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
    [audio_player.cpp, audio_test.cpp]
2026-09-11 add 5s startup delay so USB serial monitor can attach
    Native USB re-enumerates after flashing; a delay lets the monitor connect
    before the first prints. Added to both test sketches and the main firmware.
    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
2026-09-11 audio: default the test to plain HTTP (TLS is the S2 crackle cause)
    Serial showed HTTPS throughput ~37KB/s vs 24KB/s needed and heap down to 18KB —
    TLS on the single-core S2 is the bottleneck. Default TEST_URL is now a plain-HTTP
    stream; documented to host real sounds over HTTP too.
    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
    [audio_test.cpp]
2026-09-11 audio: forceMono on the MAX98357A to smooth single-core S2 playback
    Network side is healthy (HTTP, strong RSSI, 88KB heap) but crackle persisted;
    the amp is mono, so decode/output in mono halves the per-sample work.
    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
    [audio_player.cpp, audio_test.cpp]
2026-09-11 audio: drop test volume to 6 to bisect clipping vs digital glitch
    Buffers are huge (16x512 I2S DMA + 283KB net), so a constant glitch is not
    underrun. Low volume distinguishes amp/power clipping from wiring/format issues.
    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
    [audio_test.cpp]
2026-09-11 add raw I2S tone test env (no WiFi/decode) to isolate the crackle
    Generates a clean 440 Hz sine straight to I2S. Clean => wiring/amp OK and the
    crackle is streaming/decode on the single-core S2; scratchy => hardware.
    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
    [tone_test.cpp]
2026-09-11 switch main firmware audio to on-flash (LittleFS) playback
    The tone test proved the I2S path is clean — the crackle was the single-core S2
    choking on WiFi streaming + MP3 decode together. Play sounds from flash instead:
    - audio_player: LittleFS connecttoFS, forceMono, no WiFi (idle + celebration)
    - config.h: AUDIO_FILE/IDLE_FILE replace URLs; secrets.h no longer needed by main
    - platformio.ini: LittleFS filesystem + default.csv partition
    - data/: drop celebrate.mp3 / idle.mp3, upload with `pio run -t uploadfs`
    - docs updated; streaming audiotest kept for reference; tonetest is the amp check
    Claude-Session: https://claude.ai/code/ses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
    [audio_player.cpp, config.h]
2026-09-11 add fstest env: play audio from flash in isolation
    Standalone LittleFS playback test (no WiFi/motor/button) to verify the on-flash
    audio path — the fix for the streaming crackle. Lists files, loops /idle.mp3.
    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
    [fs_audio_test.cpp]
2026-09-11 enlarge audio partition to ~2MB (LittleFS was full)
    Custom partitions_audio.csv drops the OTA second app slot to give the LittleFS
    audio partition ~2MB (was ~1.4MB). App is only ~0.77MB so it fits easily.
    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
    [partitions_audio.csv]
2026-09-11 fix: loop idle audio on eof callback, not isRunning() polling
    The poll-based restart could re-trigger the file during its startup phase
    (isRunning() briefly false), stalling it at the ID3 header with no sound.
    Use the audio_eof_mp3 callback instead. fstest now plays once with progress
    diagnostics to confirm decoding advances.
    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
    [audio_player.cpp, fs_audio_test.cpp]
2026-09-11 docs: recommend 22050Hz mono (or WAV) audio encoding for the S2
    Playback crackles once the buffer drains because 44.1kHz MP3 decode can't
    sustain real-time on the single core. 22kHz halves the load; WAV has no decode
    cost at all.
    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
2026-09-11 add wavtest: raw PCM WAV player (no decode) — reliable audio path for the S2
    MP3 decode can't sustain real-time on the single-core S2 (crackles once the
    buffer drains). wav_test.cpp reads a 16-bit PCM WAV from LittleFS and feeds it
    straight to I2S, same clean path as the tone test — no decode, no library.
    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
    [wav_test.cpp]
2026-09-11 wavtest: preload WAV into PSRAM, play from RAM (fixes flash-contention crackle)
    Reading the WAV from flash during playback stalled the CPU (code also runs from
    flash) and starved I2S -> crackle. Load the whole PCM payload into PSRAM once,
    then feed I2S from RAM — no flash access during playback.
    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
    [wav_test.cpp]
2026-09-11 main firmware: raw WAV audio preloaded to PSRAM, non-blocking I2S
    The winning path from the audio debugging: preload 16-bit WAVs into PSRAM and
    feed I2S from RAM (no MP3 decode, no flash access mid-playback) — the only thing
    that's clean on the single-core S2. Non-blocking feed so audio runs alongside
    the motor + LEDs.
    - audio_player: raw ESP-IDF i2s + PSRAM clip loader; idle loops, celebration
    one-shot; per-clip volume; downmix stereo->mono
    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
2026-09-11 audio: raise volume — full digital scale in wavtest, max celebration in config
    wavtest VOL_SHIFT 1->0 (was half); CELEBRATION_VOLUME 15->21, IDLE_VOLUME 8->12.
    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
2026-09-12 boot: wait for USB serial monitor to attach before printing
    Fixed 5s delay could still miss boot output if the S2's USB re-enumerates and
    the monitor attaches late. Now wait until Serial connects (or 8s cap), so the
    banner / TMC version / diagnostics are always caught. Applied to all entry points.
    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
    [audio_test.cpp, fs_audio_test.cpp, main.cpp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]
2026-09-12 motortest: constant-speed spin for stable StallGuard tuning
    Jogging (accel/decel/reverse) made SG_RESULT swing with speed. Spin continuously
    at a constant speed so SG_RESULT holds steady and free-vs-loaded is readable.
    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
    [motor_test.cpp]
2026-09-12 tune: STALL_THRESHOLD 80->50 (free SG_RESULT measured ~150-205)
    At 80 the trip point (SGTHRS*2=160) sat above the free-running SG_RESULT (dips to
    150) -> false stalls. 50 trips at 100, clear of normal running. Also refresh the
    SGTHRS + audio comments in config.h.
    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
    [config.h, motor_test.cpp]
2026-09-12 motortest: demo real dispense + auto-unjam cycle
    Drives forward one dispense amount with accelerated motion; on a StallGuard trip
    mid-move it backs off UNJAM_REVERSE_STEPS and retries forward (up to the limit),
    then pauses and repeats every 3s. Grab the wheel to trigger the unjam.
    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
    [motor_test.cpp]
2026-09-12 fix stall false-trips: dispense at tuned speed, check only at cruise
    SG_RESULT is speed-specific and invalid during accel. Was dispensing at 1600
    (tuned at 1000) and checking during the ramp -> always "jammed". Now dispense at
    1000 and gate the stall check to >=0.9x max speed (cruise only). Applied to both
    motortest and config.h.
    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
    [config.h, motor_test.cpp]
2026-09-12 fix false jams: constant-speed motion (runSpeedToPosition) for StallGuard
    Accelerated run() has jittery step timing that wrecks SG_RESULT (~50 vs ~175 at
    the same speed with runSpeed). StallGuard needs steady timing, so dispense and
    unjam now use constant-speed runSpeedToPosition — matching how it was tuned.
    Applied to motortest and motor.cpp.
    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
    [motor.cpp, motor_test.cpp]
2026-09-12 flip dispense direction (DISPENSE_CW -> false)
    Wheel was turning the wrong way for dispensing. Flipped in config.h + motortest.
    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
    [config.h, motor_test.cpp]
2026-09-12 motortest: live SG/DIAG/dist diagnostics during dispense
    To debug why holding the wheel doesn't trigger the unjam — prints StallGuard
    state every 200ms while moving so we can see SG_RESULT/DIAG under load.
    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
    [motor_test.cpp]
2026-09-12 stall detection via SG_RESULT (UART), not the DIAG pin
    DIAG never asserted on this driver (stayed 0 even at SG_RESULT=2), so stalls were
    missed. Free SG_RESULT is ~200, a stall drops it below ~90 — so detect by polling
    SG_RESULT < SG_STALL_LEVEL (70) with a 2-read confirm. Applied to motortest +
    motor.cpp; config gains SG_STALL_LEVEL / SG_STALL_CONFIRM / SG_POLL_MS.
    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
    [config.h, motor.cpp, motor_test.cpp]
2026-09-12 add IR break-beam drop sensor: dispense until a treat drops
    - beam.{h,cpp}: debounced break-beam drop counter
    - motor.{h,cpp}: reworked to a continuous run engine with time-boxed anti-jam
    (run/stop/update); anti-jam wiggles up to ANTIJAM_TIMEOUT_MS then gives up
    - main.cpp: dispense until the beam confirms a drop (up to DISPENSE_TIMEOUT_MS),
    else fixed portion when the sensor is off (ENABLE_DROP_SENSOR)
    - config.h: drop-sensor pins/flags + dispense/anti-jam timeouts
    - beamtest env + tools/beam_test.cpp to verify the sensor
    - docs: wiring diagram now includes the break-beam sensor (DIAG wire removed;
    stall is detected over UART, not DIAG)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
    [beam_test.cpp, config.h, main.cpp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]
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2026-09-12 motortest: read back coil current from driver to confirm the setting
    Prints rms_current()/cs_actual() so you can verify 840mA actually applied
    (input-supply current at idle isn't a measure of torque).
    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
2026-09-12 bump MOTOR_CURRENT_MA 1000 -> 1500 (needs heatsink; keep <= motor rating)
    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
2026-09-12 increase dispense speed 1000 -> 2000 microsteps/s
    Faster dispense (~4.8s/wheel rev). STALL_MIN_SPEED auto-scales (0.9x max);
    SG_RESULT is speed-specific so the stall level must be re-checked at the new speed.
    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
    [config.h, motor_test.cpp]
2026-09-12 increase dispense speed to 4000 microsteps/s (AccelStepper ceiling)
    ~2.4s/wheel rev. Constant-speed instant-start may slip under load at this rate;
    if so, back off or move to a hardware step engine. Re-tune stall for the new speed.
    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
    [config.h, motor_test.cpp]
2026-09-12 wiring: lift beam 3V3/GND labels clear of the 3V3 wire
    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
2026-09-21 add illuminated push-button support: switch + LED bench test
    - config.h: PIN_BUTTON_LED (D13) + BTN_LED_* LEDC PWM/breathe params
    - buttontest env + src/tools/button_test.cpp: verifies the switch and
    drives the LED (breathing glow while idle, solid while held)
    - WIRING.md: illuminated-button section + beamtest/buttontest commands
    - wiring diagram: add the button in a new bottom band. Original generator
    was lost; render_wiring.py now composites onto wiring-motor-audio-base.png
2026-09-23 integrate full celebration sequence + WS2812 strip test
    Wire every subsystem into one behaviour in main.cpp:
    - IDLE: button LED breathes; idle sound chimes every 30 s until pressed.
    - Press: button LED off, eyes flash orange (two configurable pixel
    sections), celebration sound plays, motor dispenses with anti-jam
    until the beam sees a drop or 30 s elapses; the show runs until the
    audio finishes, then resets for the next person.
    - new button_led module (LEDC PWM breathe / off)
    - lights: add startEyes() orange eye-flash mode alongside the rainbow
    - audio: idle is now a one-shot chimed on a timer (was a continuous loop)
    - config: drop sensor enabled, 30 s dispense timeout, eye pixel mapp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
    [audio_player.cpp, button_led.cpp, config.h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]
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2026-09-28 fix celebration song cut off after ~5 s; pulse the idle glow
    Root cause: the adafruit_feather_esp32s2 board definition flashes tinyuf2.bin
    at 0x2D0000 on every app upload, which sat inside the LittleFS audio partition
    (0x1F0000-0x3F0000). Each app-only flash overwrote part of celebrate.wav, so
    the WAV loaded short and the song stopped after ~6 s (uploadfs only fixed it
    until the next app upload).
    - partitions_audio.csv: app0 1 MB, LittleFS 1.75 MB at 0x110000 ending at
    0x2D0000, and the tinyuf2 range reserved so nothing else lands there.
    - loadWav logs "TRUNCATED" when a WAV loads short instead of failing silently.
    - The idle-chime glow on pixels 60-120 now pulses yellow (IDLE_GLOW_MIN/MA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
    [partitions_audio.csv]
